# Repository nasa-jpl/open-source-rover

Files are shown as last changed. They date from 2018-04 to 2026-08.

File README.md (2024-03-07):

# JPL Open Source Rover Project

**NOTE**: For the previous major version of the OSR, please see [v3.1.0](https://github.com/nasa-jpl/open-source-rover/tree/v3.0.0).

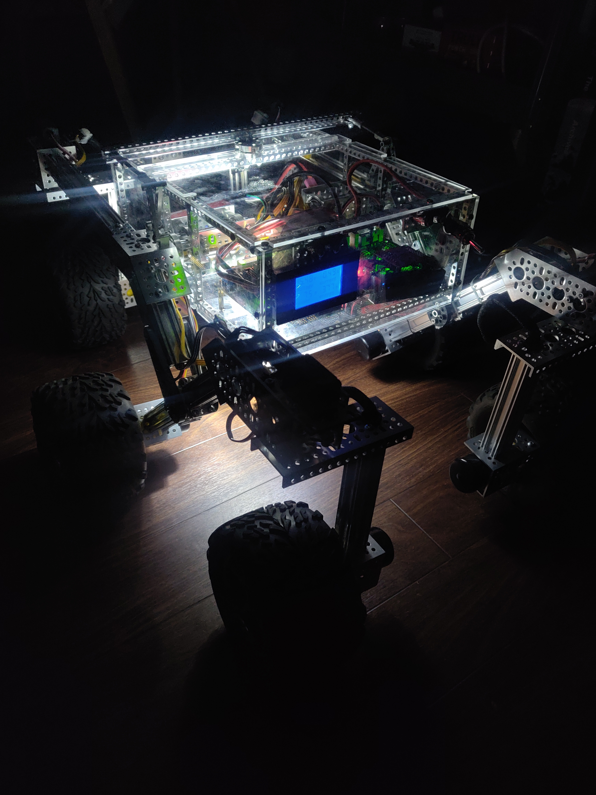
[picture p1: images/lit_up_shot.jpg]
|  |  |
| --- | --- |
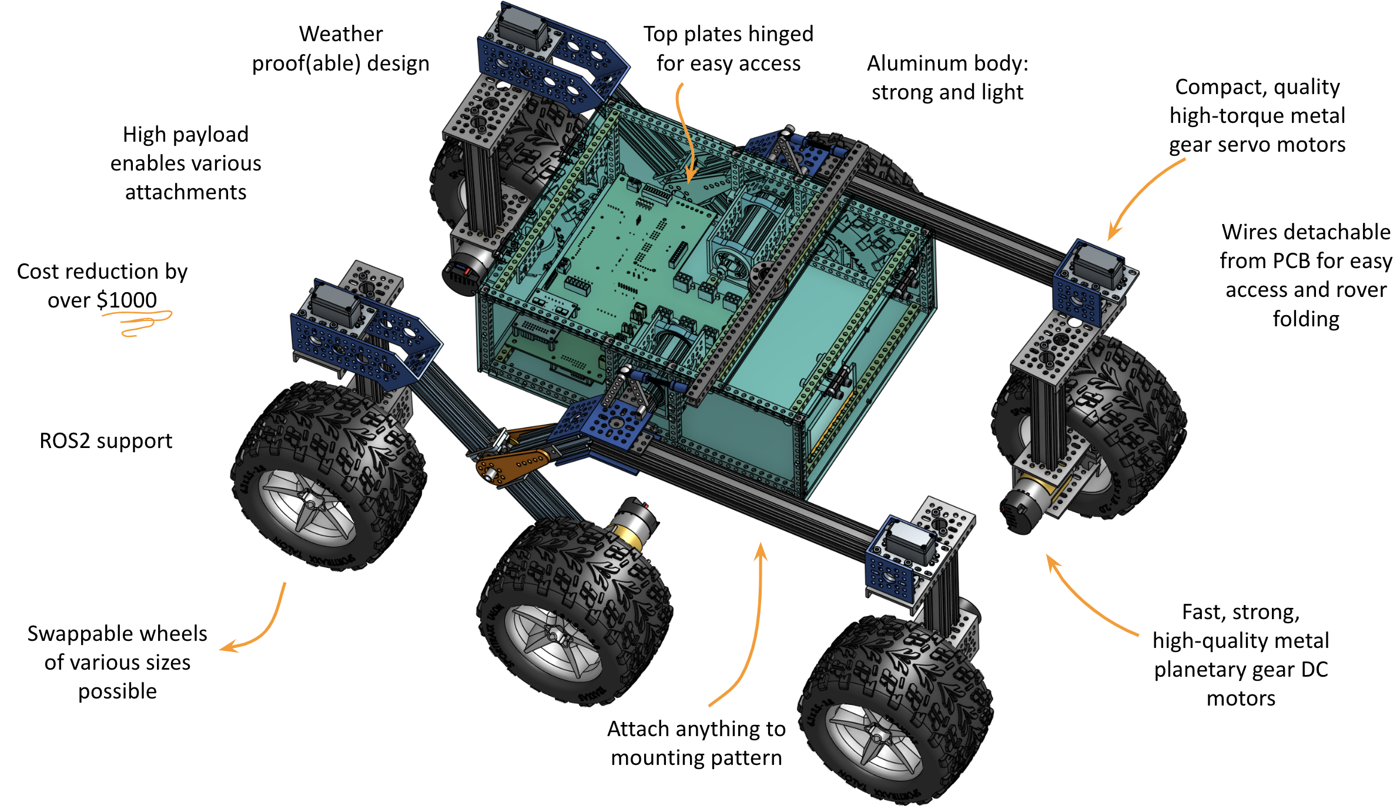
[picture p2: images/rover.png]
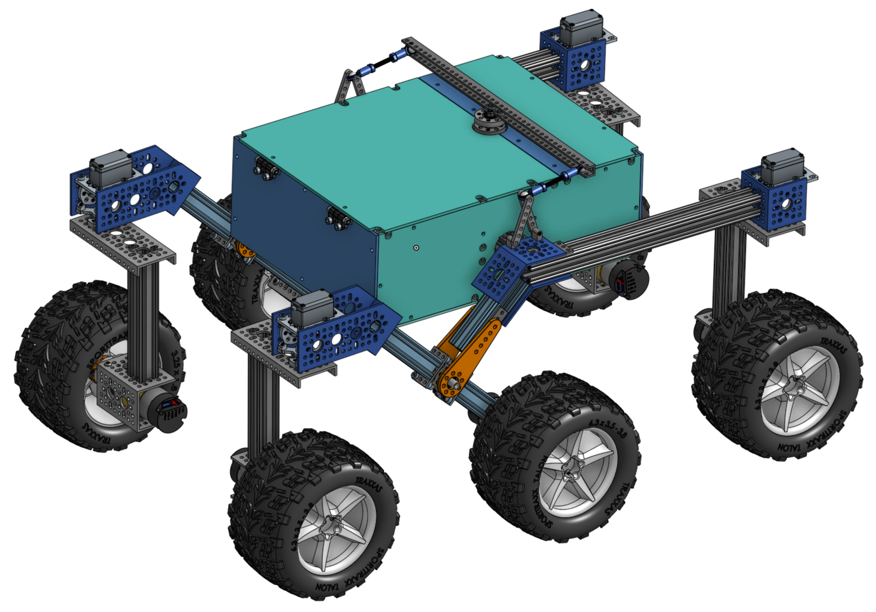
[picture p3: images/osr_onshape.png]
|  |  |

The JPL Open Source Rover is an open source, build it yourself, scaled down version of the 6 wheel rover design that JPL uses to explore the surface of Mars. The Open Source Rover is designed entirely out of consumer off the shelf (COTS) parts. This project is intended to be a teaching and learning experience for those who want to get involved in mechanical engineering, software, electronics, robotics but is also an excellent research platform for rugged terrain. No prior skills or knowledge is required.

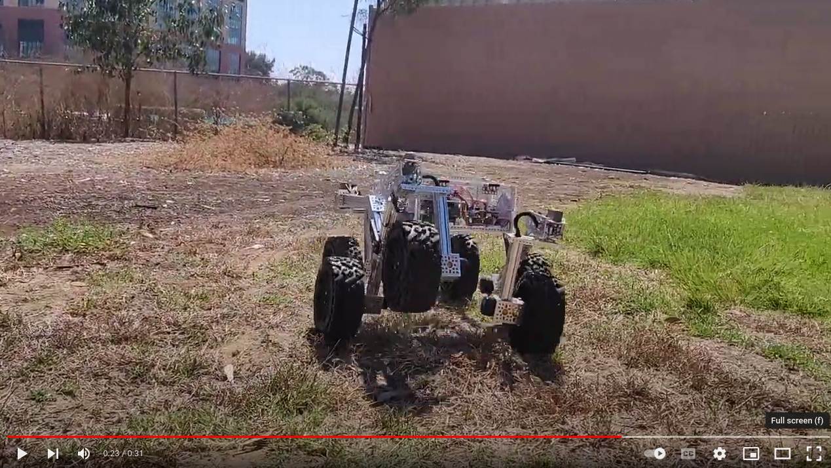
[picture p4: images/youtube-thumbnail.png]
Youtube video of OSR2 in action (https://youtu.be/exHqc_Vuifw)


A gallery of some community builds including previous versions of the rover can be found [here](examples/README.md).

## About the OSR

### Motivation

JPL is always looking to inspire the next generation of scientists, engineers, and roboticists to help us explore and learn about our solar system (and beyond!). We release the plans for this rover as a way to try and give budding enthusiasts a fun robotics project that will help teach them and get them involved in robotics sooner and at a lower cost.

### At a glance


<!-- TODO: insert terminology into gif or image: rocker bogie, ... -->

The OSR has been around since 2017 and has undergone many iterations. It is a premium and robust robot with a unique look, high customizability, and powerful abilities. The hardware and electronics were designed with expansions like a head display and robot arm in mind.

| spec | value |
| --- | --- |
| top speed | ~1.6m/s (~slow running, subject to motor selection |
| nb motors | 10 |
| structural material | aluminum |
| total cost | [~$1600](parts_list/README.md) (about the cost of a TurtleBot 3 Waffle) |



The OSR mostly uses parts from [GoBilda](https://www.gobilda.com) for the mechanical assembly. For GoBilda's (international) shipping options, see [here](https://www.gobilda.com/shipping-policy/).

Other open-source, cheaper alternatives exist but are slower, less strong, and are more fragile. See [Additional Projects](#additional-projects).

### Features

This rover is designed to function similarly to the 6 wheel rover designs on Mars and employs a few of the major driving mechanics that the mars rovers use to traverse rocky surfaces:

* **Rocker-Bogie:** The Rocker-Bogie suspension system allows all 6 wheels to continually be in contact with the ground while climbing over obstacles
* **Differential Pivot:** Allows weight to be mechanically offloaded from one side of the rover to the other while climbing
* **6-Wheel Ackerman Steering:** Driving and steering/turning mechanism that governs where the wheels point and how fast each of them will move.

A Raspberry Pi acts as the "brain" of this rover for its versatility, accessibility, simplicity, and ability to add and upgrade your own modifications. Any method with which you can communicate with a Raspberry Pi (bluetooth, WiFi, USB devices, etc) can be interfaced into the control system of the robot.

For a 7.2Ah battery and with some driving on rough terrain, expect to get at least 3 hours of drive time. Below chart was recorded while driving on rocky terrain and plots voltage, current draw, and commanded velocity over time. When the voltage drops below 13-14V, the rover will power down. You can increase drive time by getting a bigger battery and/or by having the rover carry a second battery that can be swapped out.

> *WARNING*: Be careful to not discharge a LiPo battery too far as that drastically lowers the lifetime of your battery and can potentially make it hard or impossible to recharge.

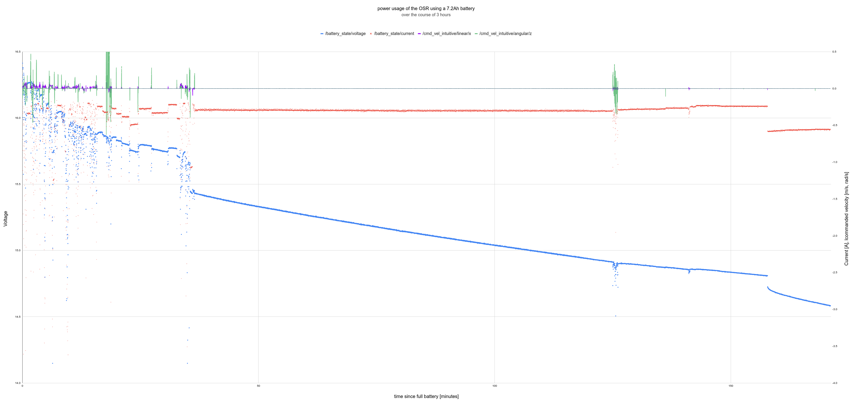
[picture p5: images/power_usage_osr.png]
power usage chart


## Join a community of hundreds of builders

Considering building one yourself? The best way to ask questions, reach maintainers, learn about modifications, and join the community of Open Source Rover builders is to join our Slack group:

<a href="https://join.slack.com/t/opensourcerover/shared_invite/zt-mfe0viua-FhcYsNb3S9vUra99uF3IBw">
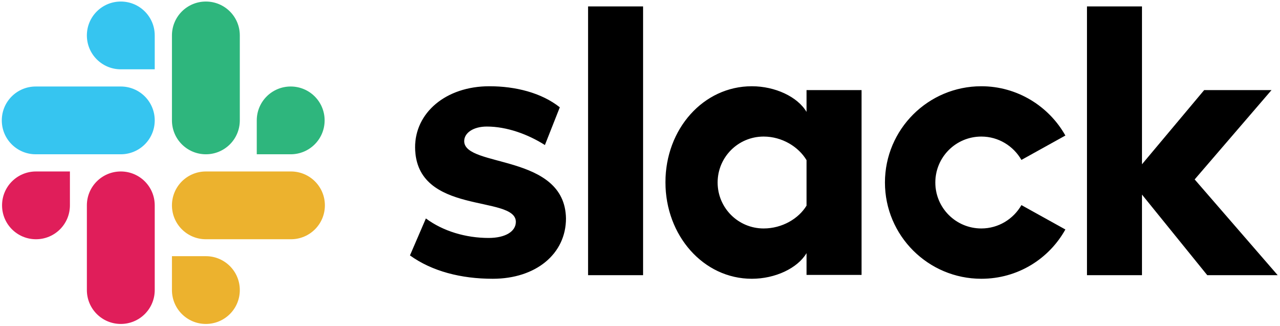
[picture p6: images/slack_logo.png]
  
</a>

**Note: JPL and Caltech have no official affiliation with this forum; it is run by individuals of the general public.** On these you can ask questions if you need help or clarification on any aspects of the project.  Additionally, you can post and promote any modifications or addons that you have created on this project. We highly encourage additions and modifications to be posted so that this project and community can grow.

### Maintenance Status

As an open-source hardware project, the rover is continuously improving. Please check [issues](https://github.com/nasa-jpl/open-source-rover/issues), [pull requests](https://github.com/nasa-jpl/open-source-rover/projects), and the Slack forum to see if any big changes are expected soon. The OSR project is proud to be Open-Source Hardware certified!

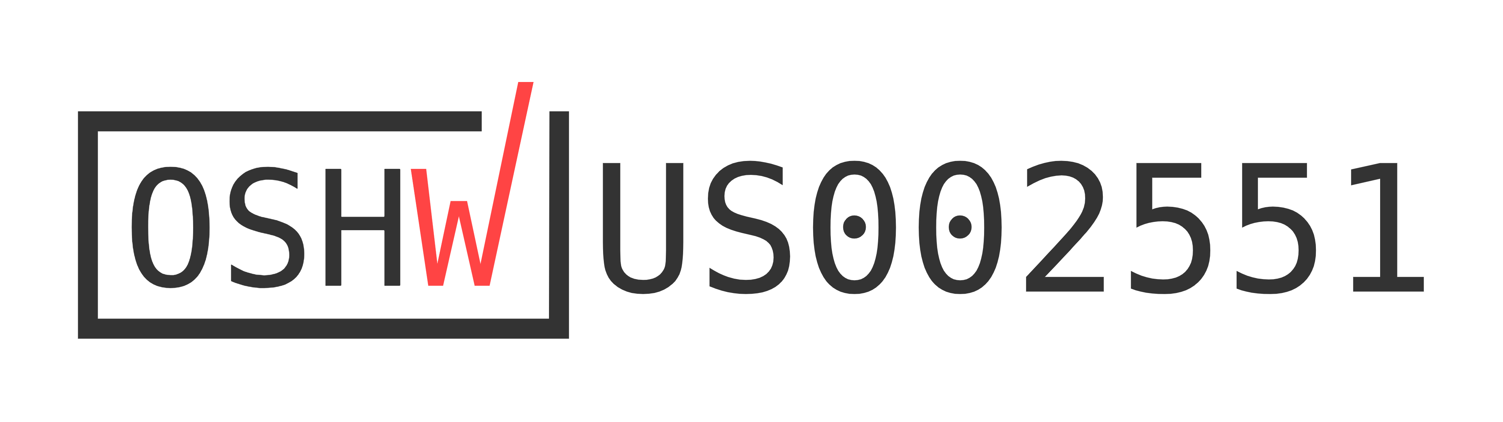
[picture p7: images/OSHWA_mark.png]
OSHW certification US002551 (https://certification.oshwa.org/us002551.html)


### Online 3D Model

You can view a 3D model of the latest version of the rover in your browser [at OnShape](https://cad.onshape.com/documents/e4f00b1a3d2edb1a84bbba1c/w/8ab8f394324bcc586236ef5d/e/9191e5ad2a70f387b419bc55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).

### Skills Necessary

This project has elements in mechanical assembly/fabrication, uses a host of electrical components, and has software that will run it all. In order to complete this project, you will need to have some experience in the following:

* **Fabrication/Machining:** All parts are Consumer Off-The-Shelf (COTS) parts and **no metal machining should be required** to complete the 'base' version of the rover. However for any optional expansions, it may be useful to have access to the following skills/tools:
  * Metal cutting using band saw/dremel
  * Drilling using drill press/hand drill
  * Filing and sanding for part cleanup
  * General Fabrication/Machining Safety
* **Electronics:** This project uses components like motors, motor controllers, and batteries. While prior experience with the following skills is not required, having access to someone who can help will save a lot of time:
  * Soldering
  * Electrical debugging
  * Wiring
  * Electrical Safety
* **Software:** The rover's brain is a Raspberry Pi. All code can be found in the [osr-rover-code](https://github.com/nasa-jpl/osr-rover-code) repository along with step-by-step instructions to set it up. Basic familiarity with Linux, ROS, Git, and Python will be helpful though.

Most of the above are skills that you can learn and pick up fairly quickly from watching videos and doing research on the internet, and throughout the project we try to give supplemental information on some of these as well. See the build documents for more information.

### Tools Necessary

This project assumes you have some standard tools to help assemble the project. If you do not have any of the optional tools, we provide examples of online services that you can use to have the parts fabricated and sent to you.

#### Mandatory tools

* Metric hex keys
* Pliers
* Wire Snips
* Wire Strippers
* Solder Iron
* Solder
* Digital Multimeter
* Wire strippers, e.g. [these](https://www.amazon.com/dp/B07DWVSR41/?coliid=ISMG8XMBILGFK&colid=1IM7RHK25RIBB&psc=0&ref_=lv_vv_lig_dp_it)

#### Optional Tools

* 3D printer
* Laser Cutter (for the body plates, online services available)
* Benchtop Power Supply (to test without using battery)
* Items for operating a Raspberry Pi (Keyboard, mouse, monitor, 5V micro USB power adapter)

### Expected time commitment

In our experience, this project takes no less than 100 person-hours to build, and depending on the familiarity and skill level of those involved could be significantly more. Experienced builders may be able to build this project in this amount of time.  However, this project is generally meant to be a teaching and learning tool.  Throughout the documentation, we try to give supplemental information for those who might be new to this kind of project.

## Getting Started

### Rover Build Roadmap

* **Stage 1:** [Order parts](#ordering-parts). You'll want to get started on this ASAP!

* **Stage 2:** [Create the wiring](electrical/wiring/README.md). The cables connect the Printed Circuit Board (PCB) in the body to each motor and integrate into the rocker-bogie and corner assemblies so they need to be built first.

* **Stage 3:** [Make the electronics](electrical/pcb/README.md): Soldering the PCB and installing into the rover along with peripheral connections. We'll also use the wiring to test your PCBs.

* **Stage 4:** [Make the mechanical assemblies](mechanical/README.md): the body, the two rocker-bogies, the drive and corner motor assemblies. The instructions will guide you through how to do these step by step while integrating the cabling from Stage 2. You'll then attach them into something that will start to look like a rover!

* **Stage 5:** Setting up and configuring the operating system rover code. The [Rover Code repo](https://github.com/nasa-jpl/osr-rover-code)'s README files will walk you through all necessary steps for getting the rover software up and running on the Raspberry Pi. These steps can be completed at any point during the project, all the way up to when all the electronics and mechanical parts are completed and you are ready to start driving and controlling the robot.

* **What's next?** Add your own upgrades! We chose Raspberry Pi as the brain of the project so that it should be easy to add, change, and upgrade to build exciting things on top of this already cool robot.  Some upgrade ideas to get you brainstorming: sonar for collision detection, IMU for orientation / closed-loop driving / obstacle mapping, camera for object identification and tracking, sensor packages (temperature, pressure, humidity), solar panels, or even a robotic arm!

### Ordering parts

#### Parts Lists

The [Parts List Readme](parts_list/README.md) contains all the parts necessary to build the entirety of the robot as it is listed in our documentation.

Note that educational builders may apply for a 15% discount at GoBilda by filling out [this form](https://form.123formbuilder.com/6143945/open-source-rover-edu-form). Make sure you do this on time as processing times may vary. 

You can select higher RPM motors (to drive your rover faster) at the sacrifice of max stall torque. A selection of motors that would integrate easily with the rest of the suggested rover design can be found at [GoBilda - 5203 series](https://www.gobilda.com/yellow-jacket-planetary-gear-motors/).
The rover design and the software can accommodate different wheel sizes if you find wheels you like better.

## Additional Projects

Take a look at these alternative Mars rover replicas:

* [Sawppy Rover](https://hackaday.io/project/158208-sawppy-the-rover)
* [ESA ExoMy](https://github.com/0xD0M1M0/ExoMy)
* [3D printed and driveable Curiosity/Perseverance inspired Rover](https://github.com/jakkra/Mars-Rover)

## Star History

Star History Chart (https://star-history.com/#nasa-jpl/open-source-rover&Date)

## Disclaimer

Reference herein to any specific commercial product, process, or service by trade name, trademark, manufacturer, or otherwise, does not constitute or imply its endorsement by the United States Government or the Jet Propulsion Laboratory, California Institute of Technology. Government sponsorship acknowledged.

Licensed under [Apache License 2.0](LICENSE.txt).

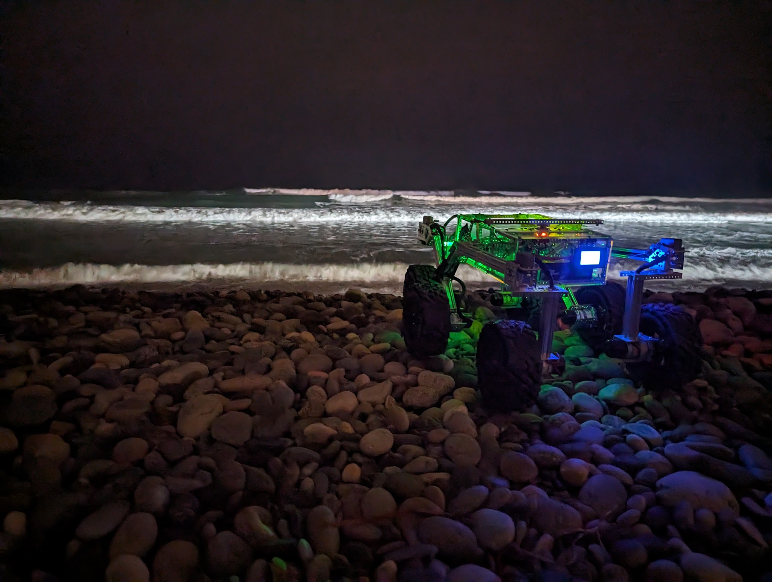
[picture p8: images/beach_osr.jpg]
OSR on the beach at night


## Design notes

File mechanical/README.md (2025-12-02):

# Mechanical Subsystem

The mechanical subsystem makes up the physical rover without any of its brains or electronics installed.

construction

The image below shows our suggested progression through the mechanical build process for this project. All individual subassemblies are meant to be completely parallelizable, so each individual subassembly could be built on its own at the same time. Once all the subassemblies are finished, there is one mechanical integration process where each of the subassemblies is integrated together to create the final rover body. Along with the pictures in each folder's README document, open the [OnShape model](https://cad.onshape.com/documents/e4f00b1a3d2edb1a84bbba1c/w/8ab8f394324bcc586236ef5d/e/9191e5ad2a70f387b419bc55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) so you can see what goes where and spin it around. Note that the OnShape model does not have all screws included to keep the model speedy and light.

## Building the subassemblies

Click on the images to get started on a subassembly!

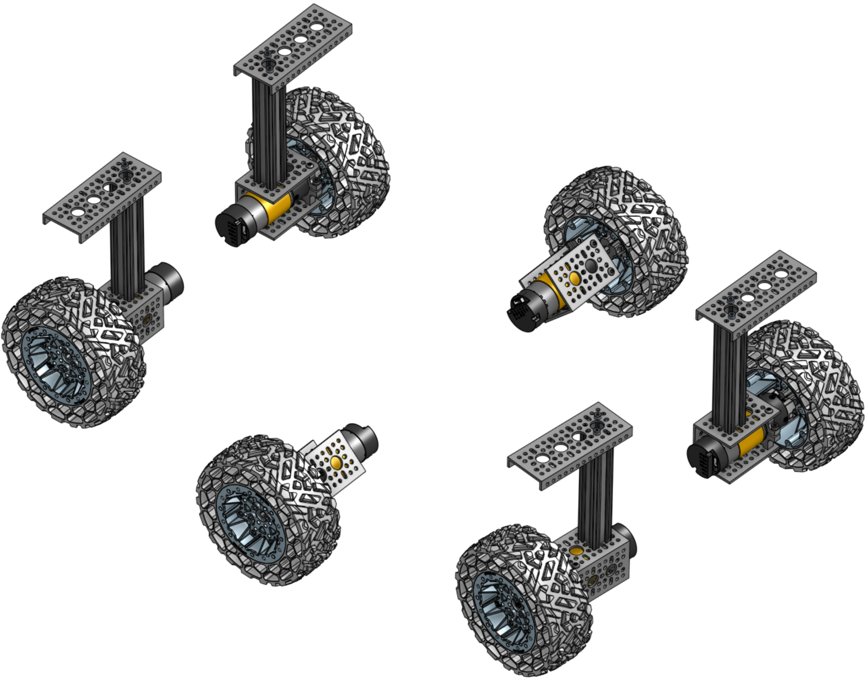
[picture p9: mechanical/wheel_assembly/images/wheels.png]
wheel assy
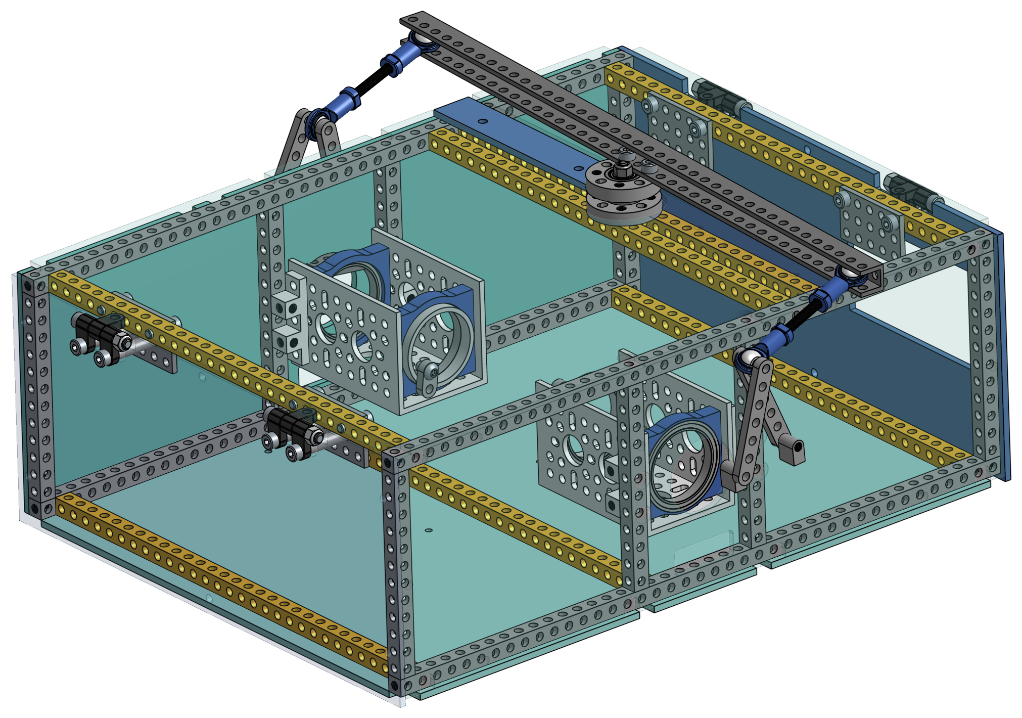
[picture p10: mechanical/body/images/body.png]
body
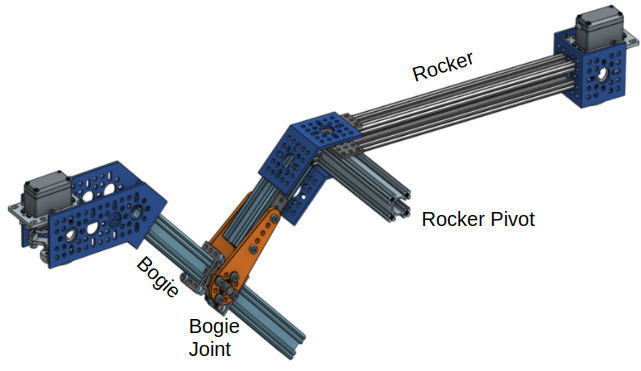
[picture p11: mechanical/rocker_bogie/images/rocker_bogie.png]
rocker bogie
|  |  |  |
| --- | --- | --- |

## Putting it all together

If you haven't already, now is a good time to attach the PCBs to the bottom body plates using the standoffs. The body plates have holes that correspond to where the standoff screws should go.

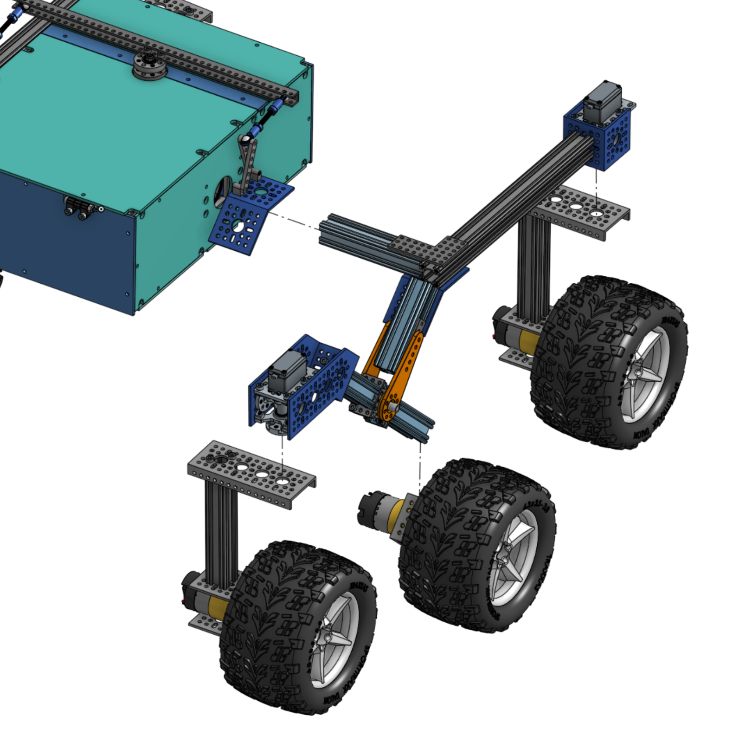
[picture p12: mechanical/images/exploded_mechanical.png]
exploded view

Inserting the left rocker-bogie in the body. Note that the 45 angle bracket in blue should already be attached to the rocker-bogie and the wheels should not be attached yet. A 32mm ID round spacer that should be installed below is also not seen on this image.
**I didn't have space on the outside of the body, just one spacer in the center**

### Inserting the rocker-bogies in the body

Line up the rocker-bogies with the body such that they can be easily inserted. It helps to put the body on a box such that the holes line up with the rocker-bogie axes. Slide a 32mm internal diameter (ID) spacer around the wires and onto the rocker-bogie axis. Then, carefully insert the wires extending from the rocker-bogie axis through the body plate hole and large diameter bearings and into the body, immediately followed by the axis itself. Repeat for the other side.

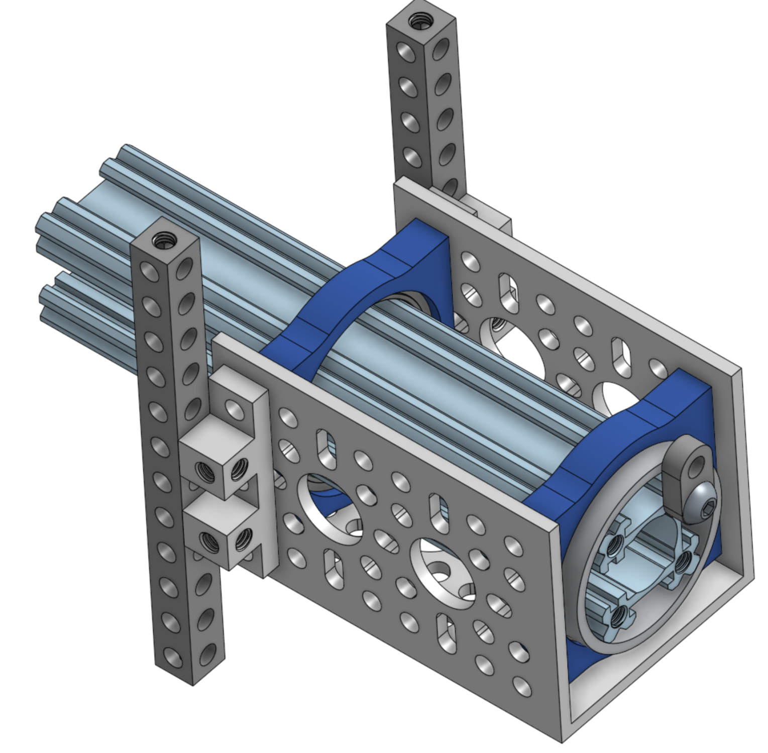
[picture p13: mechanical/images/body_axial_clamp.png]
inserting the rocker-bogie axis into the body axis assembly

Inserting the rocker-bogie axis into the body axis clamp. The rocker-bogie is not shown. The cables come out of the axis on the bottom right.

Secure the body axis to the body using another 32mm ID spacer and flat 2-hole bracket + button screw. Repeat for the other side.

### Attaching the differential pivot to the rocker-bogies

Attach the differential pivot legs to the rocker-bogie 45 degree brackets using M4x8 screws.  It may be easier to unmount the blocks, attach them to the bracket, then attach the pivot legs to them as shown in the sequence below.  A curved pair of needle-nose pliers or a hemostat is helpful to secure the M4x8mm screw while placing the block on the top, as it's hard to reach.  The button head screw that attatches to the inside leg is a bit tight.

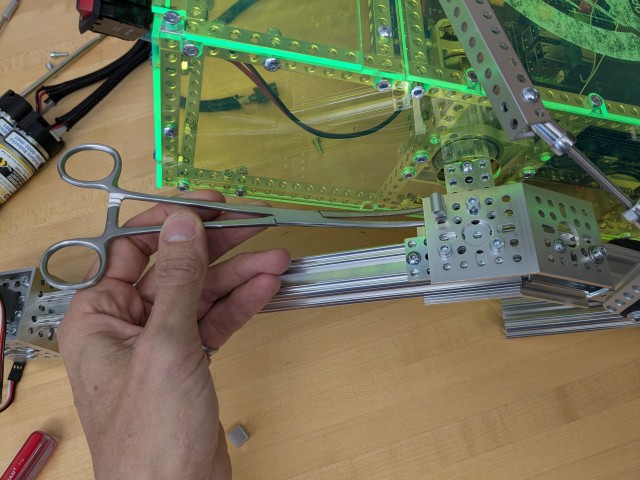
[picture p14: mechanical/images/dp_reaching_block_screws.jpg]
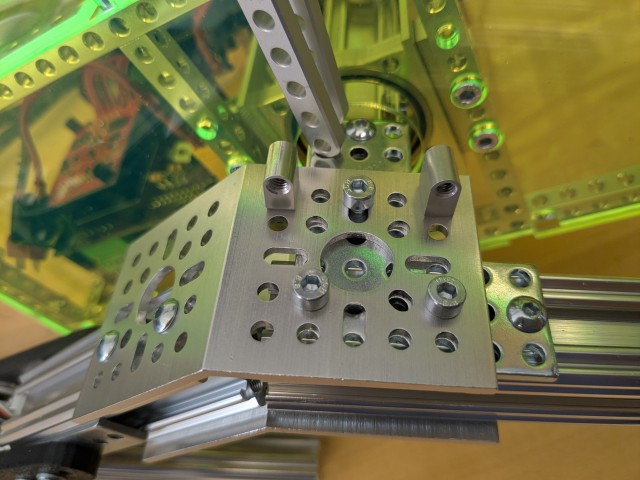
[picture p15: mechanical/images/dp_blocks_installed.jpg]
|| |
| --- | --- |
| Holding the blocks in place | Blocks Installed |

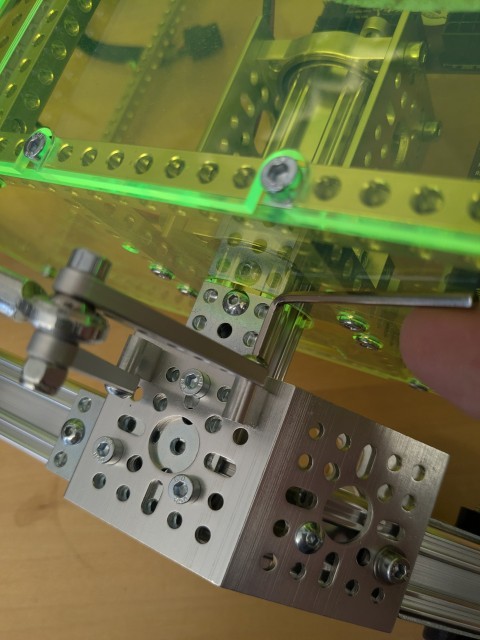
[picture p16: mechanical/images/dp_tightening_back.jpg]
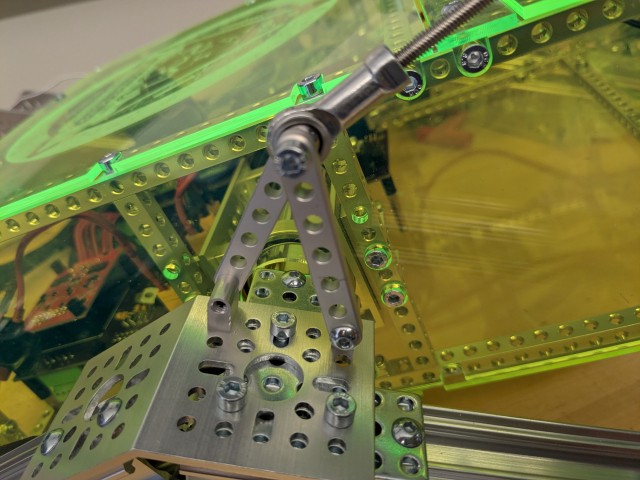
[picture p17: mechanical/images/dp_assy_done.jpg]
|| |
| --- | --- |
| Tightening the back leg | Differential Pivot Installed.

### Attaching the middle drive motors

With the help of someone else, carefully flip the rover over so we can attach the motor assemblies.

Connect the two drive motor U-channels to the rocker bogie middle legs using 3 button screws. Then insert the motor into the U-channel and secure the clamp around the motor's gearbox to the U-channel using 4 socket M4 screws. It helps to have another person around here as well to hold the motors so they don't dangle on the cables.

### Attaching the corner assemblies

Using 3 socket M4 screws, attach each corner assembly to the output shaft bracket of the servo. Making sure you connect the right corner assembly to the right side. Flip the rover over again and route the corner cabling through a hole in the bracket holding the servo. The bullet connectors and DuPont connectors from the rocker bogie and corner assemblies should meet here.

> **tip**: Now is a good time to do another connectivity check. Using your multimeter, confirm that each wire connects all the way through.

> **Maintenance note**: The corner servo gearset can sometimes be damaged in operation. See [here](servo_gear_replacement/README.md) for a guide on repairing your corner servos.

Finally, insert the PCI-E connectors inside the body and the DuPont connectors for the servo motors into the appropriate receptacles on the PCB. The silk screen lettering on the PCB informs which wire should go where. Once inserted, make sure the rocker-bogies can rotate relatively freely around the body by lifting the wheels up.

If all goes well you're done with the mechanical and electrical stages and you're ready to install the software!

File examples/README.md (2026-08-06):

# Builders' gallery

OSRs in the wild and under construction! Please [add your rover](#Instructions-for-adding-your-build) and add updates and pictures here as it evolves.

# <ins>V2 Rovers</ins>

## Coast-Ex

| <image src="images/coast-ex/coast-ex-cliff-view.jpg" height="150"> <image src="images/coast-ex/coast-ex-waterfront.jpg" height="150"> <image src="images/coast-ex/coast-ex-lidar.jpg" height="150"> <image src="images/coast-ex/coast-ex-side-view.jpg" height="150"> [<image src="images/coast-ex/coast-ex-video-thumbnail.jpg" height="150">](https://youtube.com/playlist?list=PLEVE4pbtqQmY) |
|:-:|

<details>
  <summary>Expand to learn more about this build!</summary>

### Background

COAST-EX was built in 2026 as a collaborative internship project involving SCIENTEAMA, the M2C laboratory (CNRS) and ESIX Normandie.

Our objective is to investigate how the JPL Open Source Rover can be adapted into a low-cost, modular platform for the digital surveying of beaches and coastal environments. The rover is intended to support repeatable field acquisitions for terrain mapping, LiDAR-based localization, photogrammetry, and, in future developments, other scientific sensors such as ground-penetrating radar.

The first prototype was assembled and integrated by engineering student Théo Etheve at ESIX, under the joint supervision of Xavier Pellerin Le Bas at SCIENTEAMA and Laurent Froideval at CNRS.

Initial field trials were conducted on sand, gravel, and uneven terrain to evaluate the rover's mobility and its suitability for coastal fieldwork. Real-time LiDAR SLAM was also successfully tested while the rover was moving.

### Modifications

* Replace Polulu 5V D24V150F5 by a cheaper ANGEEK 200W 15A XF0374 (https://www.amazon.fr/-/en/dp/B07ZH5QDSS?ref=ppx_yo2ov_dt_b_fed_asin_title)
* Added a top-mounted LiDAR sensor
* Integrated real-time LiDAR SLAM for mapping and localization
* Adapted the onboard software configuration to operate the LiDAR and SLAM system

### Current development

Future developments will focus on autonomous navigation, repeatable surveying trajectories, terrain mapping, camera-based acquisition, and the integration of additional coastal monitoring sensors.

### Media

* [Field test videos](https://youtube.com/playlist?list=PLEVE4pbtqQmY)

</details>

## Phoenyx-I ([PUCRA](https://github.com/PUCRA/Phoenyx-I))

| <image src="images/Phoenyx-I/Phoenyx-I 1.jpg" height="175"> <image src="images/Phoenyx-I/Phoenyx-I 2.jpg" height="175"> <image src="images/Phoenyx-I/Phoenyx-I 3.png" height="175"> |
|:-:|

<details>
  <summary>Expand to learn more about this build!</summary>

### Background
We are a robotics association formed by university students.

We decided to participate in the SENER CEA Bot Talent 2025 competition in order to learn and deepen our knowledge in robotics. As a result, we achieved great success, winning both the Design Award and the Overall Award, and successfully completing three challenges: perception, localization, and control. The competition was focused on using the JPL rover to carry out the challenges.

After the competition, we carried out several demonstrations and implemented multiple improvements to both the robot and its software in order to continue learning and improving the system.

### Modifications
* Added an Orbbec Astra Pro Plus (RGB-D camera)
* Added a YDLidar X4
* Added an Adafruit BNO055 IMU
* Added an Arduino to control a NeoPixel LED to indicate the robot state
* Added an emergency button
* Added a ventilation system with dust protection
* Replaced the RoboClaw 2x7 with the RoboClaw 2x15 motor drivers
* Added PLA covers for decoration and protection of motors, servos, robot profiles, and sensors

</details>

## jerrys_rover ([jerryok826](https://github.com/jerryok826/rover-monitor  ))
| <image src="images/jerrys_rover/rover_lawn_1.jpeg" height="175"> <image src="images/jerrys_rover/rover_monitor_pcb.jpg" height="175"> 
|:-:|

<details>
  <summary>Expand to learn more about this build!</summary>

### Background
I always wanted to build an outdoor rover so I started building the JPL rover in May 2025. It took me a couple of months to build it but it was great fun. I learned a lot along the way especially after not using Loctite, the screws loosened and left me with a trail of nuts and bolts in the backyard.
### Modifications
* Added OLED info display with shutdown and run buttons.
* Audible alarm for of battery state.
* Make one yourself [here](https://github.com/jerryok826/rover-monitor)

</details>

## Resilience (res) ([murphcj](https://github.com/murphcj))
| <image src="images/Resilience/Resilience_Lighthouse.jpeg" height="175"> <image src="images/Resilience/Resilience_Ocean.jpeg" height="175"> <image src="images/Resilience/Resilience_at_School.jpeg" height="175">
|:-:|

<details>
  <summary>Expand to learn more about this build!</summary>

### Background
Resilience was our first foray into robotics and has done several show-and-tells at the local elementary schools (driving over kids, Teachers, and the Principal!). The name comes from the book "A Rover's Story" by Jasmine Warga. This was a family project we started in January of 2024 and finished in February 2025. We hope to add more to this build in the future.

### Modifications
* TBD...

</details>

## Scout ([Scout](https://github.com/igillespie))
| <image src="images/scout/scout_1.jpeg" height="175"> <image src="images/scout/scout_mast.jpeg" height="175"> <image src="images/scout/website.jpeg" height="175"> |
|:-:|

<details>
  <summary>Expand to learn more about this build!</summary>

### Background
This was a family project we started in November of 2024. Our goal for this project was to build a rover that we could remotely teleoperate from our house and have the rover drive around our town. 

### Modifications
* Pan and tilt mast that houses a camera. Pan and tilt controlled by two servos.
* BNO085 IMU to help improve odometry
* Currently the rover stays connected to the internet via a Verizon "Jetpack" cellular puck. Stretch goal is to add a more integrated cellular connection with GPS
* Custom website that allows us to control the rover and its mast and monitor its status
* Flask and websockets to manager the website and streaming data

</details>

## TMUMechE ([TMUMechE](https://github.com/TMUMechE/open-source-rover))
| <image src="images/TMUMechE/RoverPic1.png" height="175"> <image src="images/TMUMechE/RoverPic2.png" height="175"> |
|:-:|

<details>
  <summary>Expand to learn more about this build!</summary>

* Project began in January 2024 with a team of 3 seniors studying mechanical engineering at The Master's University, and the help of a senior in computer science
* Intended to be a platform for future classes at The Master's University to build on the work we have started

### modifications
* Check back here for modifications coming soon!

</details>

## Bobert ([Adriel](https://github.com/abust005/open-source-rover))
| <image src="images/bobert/bobert_front.jpg" height="175"> <image src="images/bobert/bobert_side.jpg" height="175"> <image src="images/bobert/bobert_back.jpg" height="175"> |
|:-:|

<details>
  <summary>Expand to learn more about this build!</summary>

* Construction started in October 2023 as a first personal dive into robotics 
* Intended as a learning experience, and as a general robotics platform for exploring computer vision and navigation algorithms

### modifications
* **OAK-D + mount**: Bobert has an original run OAK-D from the first Kickstarter for his eyes, plus a custom pan-tilt mount I designed and had printed in nylon with multi-jet fusion (MJF). The mount uses two pancake stepper motors driven my a SPI-controlled stepper driver board
* **Tool rack**: For field maintenance and repair, I've added a small rack using some wooden dowels and some 3D-printed brackets to hold my Wera ratchet in place on Bobert
* **On/off switch mount**: To prevent the on/off switch just flopping around, I've added a small 3D-printed switch mount

</details>

## Raf the Rover ([Achille](https://github.com/Achllle))

| <image src="images/raf/raf_roof_rack.jpg" height="150"> <image src="images/raf/osr_outside.jpg" height="150"> |
|:-:|

<details>
  <summary>Expand to learn more about this build!</summary>
  
### background

* This is my second rover! I built the first one [Robert the Rover](#robert-the-rover-achille) in 2019. This version is the original v2 of the OSR, which I lead the mechanical design of.
* It was featured on [Hackaday](https://hackaday.com/2023/09/16/open-source-rover-gets-an-update-for-easier-building/)

### modifications

* I built a roof rack for it so that it could carry stuff around. As you can see from my first rover's mods, I switched to a roof payload holder instead of a trailer cart since that makes doing autonomy easier and lowers the chance of slipping.

</details>

## Samwise ([Eric](https://github.com/ericjunkins))

| <image src="images/samwise/samwise_front.jpg" height="150"> <image src="images/samwise/samwise_side.jpg" height="150"> <image src="images/samwise/ring_bearing.jpg" height="150">|
|:-:|

<details>
  <summary>Expand to learn more about this build!</summary>
  
### Background

* This is a custom spin-off of the OSR V2 design, utilizing mostly the same electronics and software stack, but made out of a combination of laser cut aluminum and 3D printing technologies such as MJF, SLA, and SLS. It was inspired by my partner who asked for a ring bearer robot at our wedding, and this project was particularly special to us as I was working on designing the very first Open Source Rover at JPL when we met. 

### Modifications

<table>
  <tr>
    <td width="50%">
      Custom channels, creating the structure and allowing cables to be routed through the interior of the robot, sealing from elements, and keeping cables well protected. 
    </td>
    <td>
      <image src="images/samwise/rocker_bogie_inside.PNG" >
    </td>
  </tr>
  <tr>
    <td width="50%">
      Added a servo and servo mounting block + gears in order to give the head an articulated axis, making it so I could make the head rotate around. Hollow tube supports mounts the head to run cables, and mounts an LCD screen at the top. 
    </td>
    <td>
      <image src="images/samwise/head_pivot_mechanism.PNG">
    </td>
  </tr>
  <tr>
    <td width="50%">
      Wrote a ROS backend + FastAPI, and React frontend to display either a cute face, or diagnostic information about what's happening on the robot. Gui shows things like wheel speeds, servo positions, battery voltage level, and a few error/faults.
    </td>
    <td>
      <image src="images/samwise/gui.PNG">
    </td>
  </tr>
  <tr>
    <td width="50%">
      Added corner latches that swing up/down and attach via magnets, allowing me to lock out the corners so they can't move for transportation. 
    </td>
    <td>
      <image src="images/samwise/corner_stops.jpg">
    </td>
  </tr>
</table>

</details>

# <ins>V1 Rovers</ins>

## JPL Rover

| <image src="images/jpl_rover/rover_at_open_house_1.jpg" height="350"> <image src="images/jpl_rover/rover_at_open_house_2.jpg" height="350"> |
|:-:|
| <image src="images/jpl_rover/jpl_rover_1.jpg" height="350"> <image src="images/jpl_rover/dsub.jpg" height="350"> |
|:-:|

<details>
  <summary>Expand to learn more about this build!</summary>
  
* Constructed in 2017, upgraded many times since!
* JPL has used this rover for many different events, from JPL/Mars outreach events, taking it to schools, local robotics clubs, and even a few robotic conferences!
* Maintained by a few different JPL employees over the years
  
### modifications

* Annodization! Before assembly of this version we got the metal pieces annodized a mix of red/black
* Micro D-Sub connectors at each of the rocker-bogies, so that both can be taken off easily and rover can be transported much easier!
  * [micro d-sub male](https://www.digikey.com/en/products/detail/itt-cannon-llc/M83513-03-D04N/2432917)
  * [micro d-sub female](https://www.digikey.com/en/products/detail/itt-cannon-llc/MDM-25SH006B/10491746)
* JPL Beanie! :)
  
</details>

## Robert the Rover ([Achille](https://github.com/Achllle))

| <image src="images/robert/robert1.png" height="150"> <image src="images/robert/robert2.jpg" height="150"> |
|:-:|

<details>
  <summary>Expand to learn more about this build!</summary>
  
### background

* I started construction in December 2019. Robert took his first steps about 3 months later.
* I use the rover for fun,
* I help maintain the two repositories. I'm a robotics engineer by training and happy to help with anyone stuck or with ideas. The best way to reach me is via Slack.

### modifications

* **bigger battery**: Robert runs off of [this 9Ah LiPo battery](https://www.amazon.com/gp/product/B07YP73LMX/ref=ppx_yo_dt_b_search_asin_title?ie=UTF8&psc=1)
* **RC**: For outdoor roving, I use a long-range [transmitter](https://www.amazon.com/gp/product/B08CKWZWPR/ref=ppx_yo_dt_b_asin_title_o03_s00?ie=UTF8&psc=1) and [receiver](https://www.amazon.com/gp/product/B07ZK1R32H/ref=ppx_yo_dt_b_asin_title_o02_s00?ie=UTF8&psc=1) from Spektrum.
* **sensor stack**: I mounted a lidar on top of my rover to allow for 2D mapping, localization, and navigation. I also have mounted (variations of) two monocular cameras, an IMU, and depth cameras to it. Details in [my blog post](https://www.freedomrobotics.ai/blog/how-to-pick-navigation-sensors-for-autonomous-mobile-robot).
* **toy trailer**: I bought this [toy trailer](https://www.amazon.com/gp/product/B0002HZQGO/ref=ppx_yo_dt_b_search_asin_title?ie=UTF8&psc=1) so that Robert can carry a payload. I attached it to Robert using a repurposed wrench and a collar clamp. It's not very robust but [it does the trick](https://youtu.be/caqx-S-_gv8)!
* **handle**: I used a strong piece of rope and a small piece of PCV tubing (handle) to lift the rover off the ground so I could carry it up and down stairs.
  
### blogs

  1. [Deploying on Mars: NASA-JPL Open Source Rover](https://www.freedomrobotics.ai/blog/building-the-nasa-jpl-open-source-rover)
  2. [Deploying on Mars: How to Pick Sensors to Enable Navigation for Your Autonomous Mobile Robot (AMR)
](https://www.freedomrobotics.ai/blog/how-to-pick-navigation-sensors-for-autonomous-mobile-robot)
  3. [Deploying on Mars: Rock solid Odometry for Wheeled Robots
](https://www.freedomrobotics.ai/blog/tuning-odometry-for-wheeled-robots)
  4. [Deploying on Mars: Rock solid Odometry for Wheeled Robots](https://www.freedomrobotics.ai/blog/deploying-on-mars-mapping-localization)

</details>

## Paddy-Rover ([Kit](github.com/apollokit))

| <image src="images/paddy/paddy1.jpg" height="150"> <image src="images/paddy/paddy2.png" height="150"> |
|:-:|

<details>
  <summary>Expand to learn more about this build!</summary>

  * I built Paddy through the winter of 2019-2020. She was (kinda) a covid baby!
  * It's been a great learning experience building and maintaining Paddy.
  * I help maintain the two repositories!
  
</details>
  
## Sinuhe's rover

| <image src="images/sinuhe/sinuhe1.png" height="250"> [<image src="images/sinuhe/video_icon.png" height="250">](https://youtu.be/jEhQtxJgvEM) |
|:-:|
  
<details>
  <summary>Expand to learn more about this build!</summary>

  This project help us get through covid year 2020!
  
  | <image src="images/sinuhe/electrical1.png" height="250"> <image src="images/sinuhe/electrical2.png" height="250"> |
  |:-:|
  
</details>
  
## Alex' rover
  
https://user-images.githubusercontent.com/14060847/160306700-88ff7ab6-efe0-483a-8637-53a57874fb1f.mp4
  
## Roverto ([toebes](github.com/toebes))

| <image src="images/roverto/roverto.jpg" height="150"> <image src="images/roverto/roverto_climbing_wheel.jpg" height="150"> |
|:-:|
<details>
 <summary>Expand to learn more about this build!</summary>

Built by the [Cardinal Gibbons Robotics](https://www.cghsnc.org/campuslife/co-curricular/robotics) team for use at outreach events.  Roverto has been to a few places, but is most at home on our [Mars Map courtesy of the Aldrin Foundation](https://aldrinfoundation.org/giant-mars-map/).  With it Roverto has been to:

* Astronomy days at the [North Carolina Museum of Natural Sciences](https://naturalsciences.org/) Three times.  One time Roverto had the opportunity to try and drive over a full size Curiosity wheel.  The last time we rand that event, there were over 14,000 attendees.
* [Galaxycon](https://galaxycon.com/pages/raleigh) Twice!
* The [North Carolina Transportation Museum](https://www.nctransportationmuseum.org/)
* Many events at [Cardinal Gibbons High School](https://www.cghsnc.org/).

### Enhancements

* The drive motors have been replaced by [Rev Robotics Core Hex Motors](https://www.revrobotics.com/rev-41-1300/) to give better torque
* The LED display has been updated with a [10" HDMI Touchscreen](https://www.sunfounder.com/products/10inch-touchscreen-for-raspberrypi).  We have a custom HTML web page which shows Roverto's face.
* Roverto has a custom development stand that lifts all the wheels off the ground for easy testing.

### Media
* [@robotics_cghsnc](https://twitter.com/robotics_cghsnc)

</details>

## USAi Labs AUDACITY ([JHPHELAN](github.com/JHPHELAN))

| <image src="images/AUDACITY/Houston-Robotics-Fidelity cropped.jpg" height="150"> <image src="images/AUDACITY/IMG_4751.JPG" height="150"> <image src="images/AUDACITY/IMG_3927.JPG" height="150"> <image src="images/AUDACITY/IMG_3931.JPG" height="150"> |
|:-:|
| AUDACITY 01 video (https://www.youtube.com/watch?v=n0Rx8EbABIY) |

<details>
  <summary>Expand to learn more about this build!</summary>
  
  ### Background
  * Started August 2019 as soon as we heard about the release of the NASA-JPL Open Source Rover
  * Named first version "Fidelity" to be as close to the NASA-JPL version as possible
  * Once initial parts had arrived, had a "part picking party" 
  * - with instructions from the manual for various sub-assemblies passed out, ziplock bagged & labeled
  * Sub-assemblies then assembled in groups
  * Had first roll-out almost exactly 1 year later after multiple delays, modifications, and frustrations as seen in .mp4 above
  
  ### Modifications
  * New version of rover named "AUDACITY" to be as boldly upgraded as possible to ultimately be autonomous
  * Raspberry Pi 3 >> Raspberry Pi 4b 4GB.  Perhaps later >> Jetson NANO to permit onboard AI "on the edge"
  * Raspbian >> Ubuntu 20.04
  * hand-coded Python >> ROS >> ROS2 Foxy
  * Upgraded PCB.  Looking forward to Rev F!
  * Upgraded drive & steering motors
  * Custom front/back acrylic panels
  * Emergency "Bop to Stop" switch.  Abandoned to free up room
  * Key fob remote power "Kill Switch" for range safety.  
  * - to substitue RoboClaw e-stop pins in future to stop motors but not CPU
  * Arduino driven LED "head" >> onboard LCD monitor - work in progress
  * Addition of cameras: Picamera, USB camera, Intel RealSense D450 Depthcamera, OAK-D Depthcamera |
  * - all works in progress and fraught with frustrations
  * Front bright LED "headlights" wired in parallel with drive motors.  Since polarity matters, only on when driving forward
  * Plan steering motors >> servos at some point

  ### External links
  1. [USAi Labs and Houston Community College  First rollout of rover](https://www.youtube.com/watch?v=2Wdgss0q63s)

</details>

## Instructions for adding your build

1. We'll be needing a little bit of git skills here. Although not strictly necessary, it helps to take a look at some tutorials on contributing using git & GitHub. Here are the basic steps.
   1. install git on your computer. On Linux, that means `sudo apt-get install git`
   2. Fork this repository by clicking the `Fork` button in the top right corner of the GitHub page.
   3. 'Clone' your fork to your computer by clicking the green `Code` button and copying the link. Type in `git clone` into your terminal and paste the link you just copied.
   4. Create a new branch and switch to it. `git checkout -b ourrovername_gallery`
   5. You're ready to start making changes! You can use any text editor of your liking, like [VS code](https://code.visualstudio.com/).
2. copy over someone else's section and adjust it to include your build's information. Add your entry to the top of the relevant section (V1 or V2). To keep this compact, add any text and details to the collapsible section (within the `<details> </details>` tags).
3. Create a new folder within [the images folder](./images) and add your rover's pictures to it.
4. Change the image links to point to your images. The format for that is `image src="images/your_folder_name/your_picture.jpg"`.
5. Commit your changes with git.
   1. in the terminal, navigate to this folder. `git status` should show that there are changes and new files.
   2. use `git add folder_name/file_name` for each change you want to include to stage those files.
   3. Commit these changes: `git commit -m "Adding my rover to the OSR gallery!"`
   4. Upload them using `git push origin ourrovername_gallery`, replacing `ourrovername_gallery` with the branch name you created earlier.
6. Create a Pull Request (PR) to suggest merging your code into the main branch.
   1. Navigate to the repository's [pull request page](https://github.com/nasa-jpl/open-source-rover/pulls) on GitHub. Click 'New pull request'.
   2. click 'compare across forks'.
   3. Select your fork from the head repository dropdown and pick your branch.
   4. click 'create pull request'. GitHub will take you to a page where you can create a title of your suggested changes and a description.
7. Wait for a maintainer to review your changes. They might ask you to make changes if something doesn't look right. Once the PR has been greenlighted, your changes will be added to the main branch!

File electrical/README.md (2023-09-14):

# Electrical

Please refer to the [PCB assembly](pcb/README.md) and [wiring](wiring/README.md) instructions.

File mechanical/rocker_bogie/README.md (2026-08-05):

# Rocker-Bogie Suspension

The Rocker-Bogie is the suspension system that enables the rover to climb aggressive obstacles. The design allows all 6 wheels to be in contact with the ground as much as possible, increasing traction.  The suspension system on a typical consumer vehicle can traverse obstacles about half the height of one wheel; the Rocker-Bogie suspension system can traverse obstacles over 2 times the height of the wheel.

rocker bogie

## Features

* Modular link lengths give the ability to customize rover geometry
* Optimized for climbing in the forwards direction
* Rigid support structure resists lateral bending/twisting about the Bogie joint

## Mechanical Interface/Attachments to Rover

* Servo block output shafts connect to corner motor assemblies
* rocker-bogie connects to the body axis clamp via two brackets that are detailed in the [body assembly section](../body/README.md#assemble-the-bearing-support-structures-that-connect-to-the-rocker-bogie)
* middle drive motor connects to the extruded shaft at the bottom

## Assembly

You will be creating two almost identical assemblies. Below instructions are for one side. We recommend building one side first rather than trying to build both sides in parallel, that way you'll be able to make the other side faster. Before you start building, familiarize yourself with the details of this assembly, in particular because you'll be building two assemblies that are mirrorred. Specifically, you'll want the open slits on the bogie to be facing the same side:

| close up showing slits                         |
| ---------------------------------------------- | 
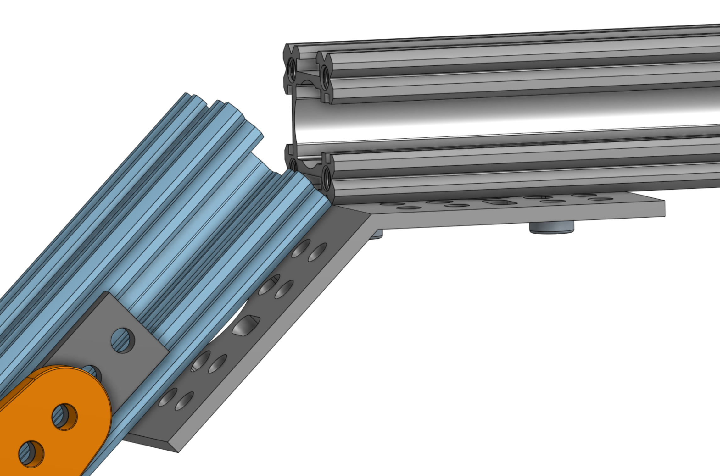
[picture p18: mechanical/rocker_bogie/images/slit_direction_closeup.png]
|   |

### Creating the rocker-bogie joint

First, gather the parts you'll need for the joint that connects the rocker to the bogie.

| Joint Parts |
| ---------------------------------------------- | 
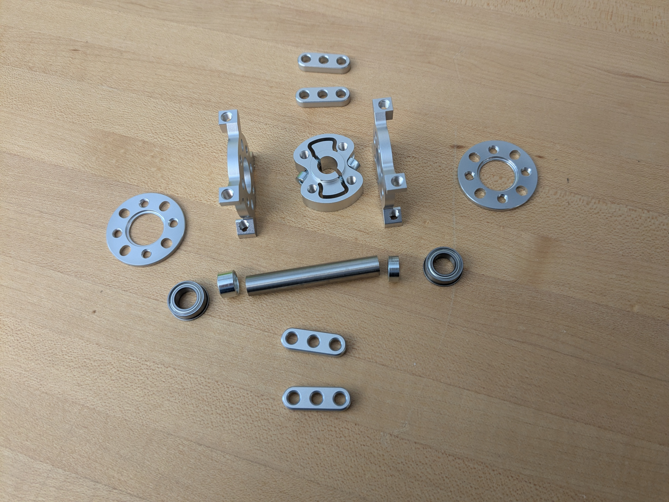
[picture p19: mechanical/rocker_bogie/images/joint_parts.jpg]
|   |

Assemble the joint following the steps below. Since the clamp in the middle isn't symmetric and protrudes on one side, two spacers of different lengths are used. You can see this in the top left image. You'll use spacer `1522-0010-0040` of length 4mm on the side of the clamp that has the protrusion, while on the other, flat side, you'll use spacer `1514-0010-0060` of length 6mm. This creates a tight assembly that prevents the joint from flexing from side to side.

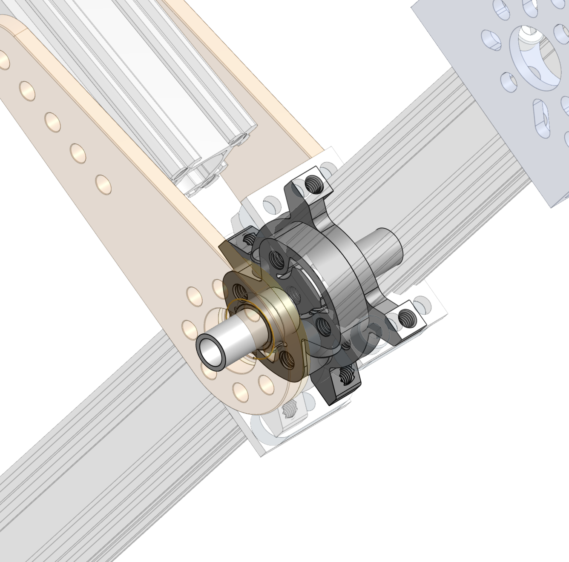
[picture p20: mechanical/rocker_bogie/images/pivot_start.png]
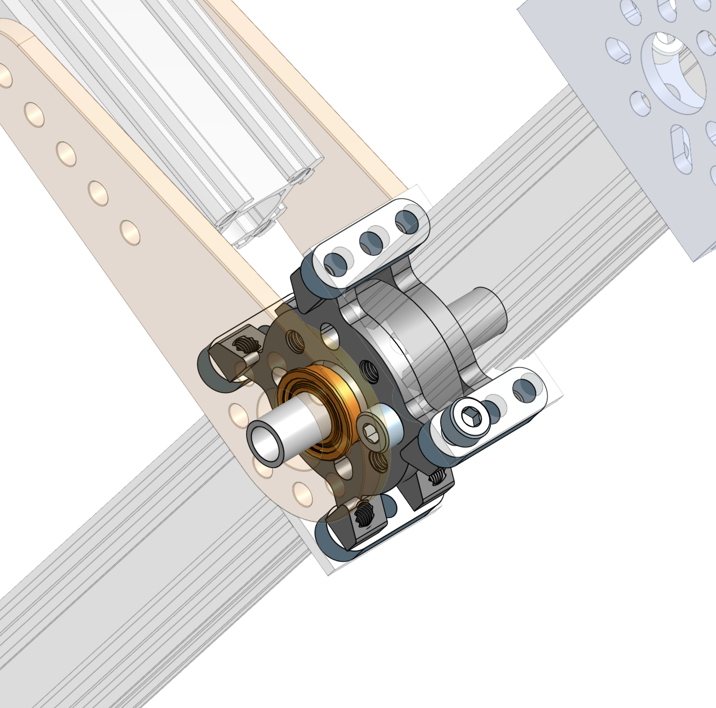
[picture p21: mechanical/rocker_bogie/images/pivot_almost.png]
|  |  |
| --- | --- |
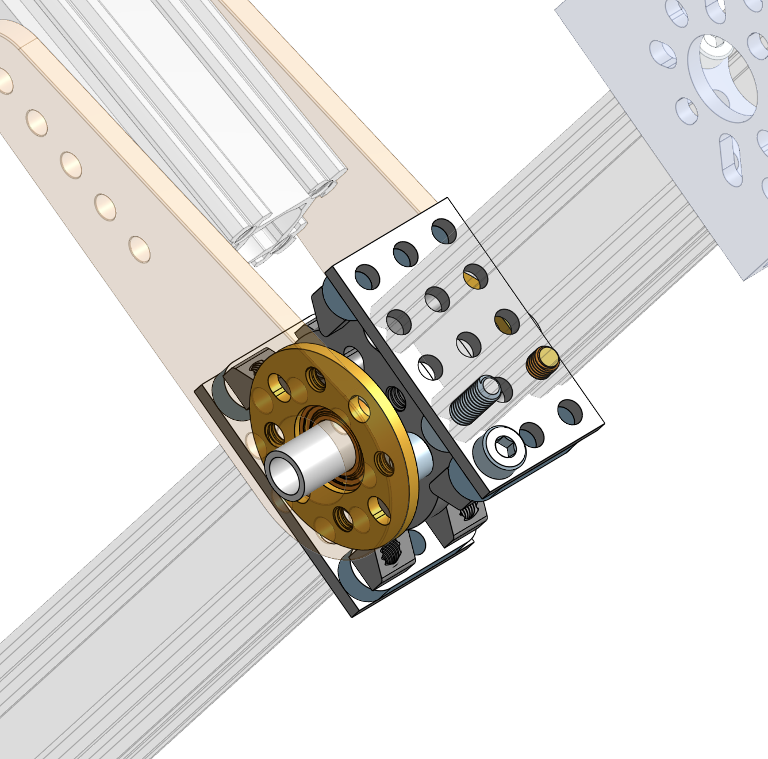
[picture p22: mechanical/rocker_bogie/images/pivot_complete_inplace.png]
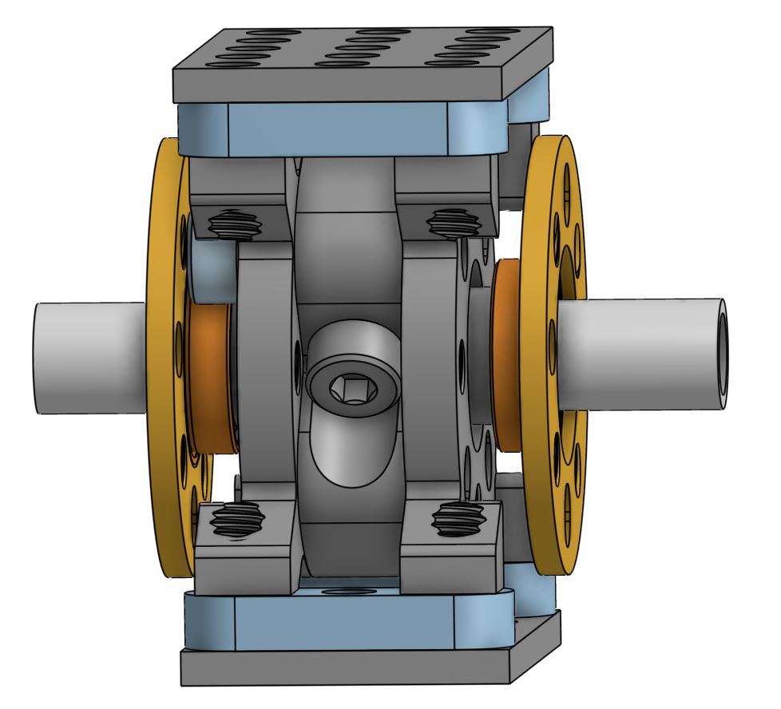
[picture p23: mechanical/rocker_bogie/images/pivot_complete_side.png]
|  |  |

Wait with the yellow and orange (ball bearing) parts. The bearing should first be inserted into the yellow hub.

> **Tip**: Use the OnShape model and navigate to the tab 'rocker-bogie' in the bottom to isolate this assembly. Then right click on various parts to temporarily hide them so you can see how the assembly works in 3D.

### Attach the control arms to the joint bearings

Referencing the orange and yellow parts in the image below, connect the hub (yellow) with the inserted bearing to the control arm using 8x socket or button M4 screws of length 12mm (or 10mm). Use washers so that the screw doesn't bury itself in the plastic control arm and to make sure the screw doesn't extend (much) on the insides of the hubs. When done, the bearing should not be able to fall out. Put these two assemblies aside for now. We'll connect each finished joint to the rockers in the following step.

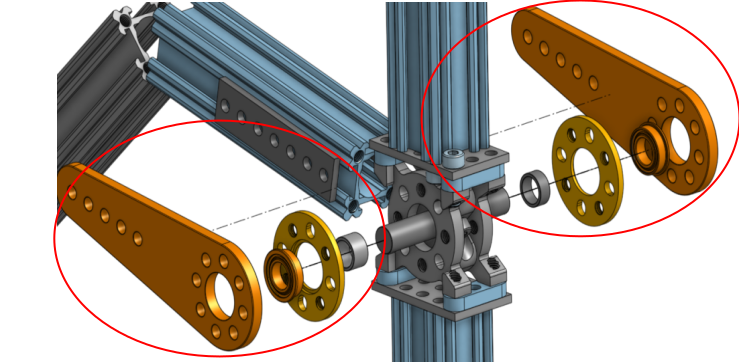
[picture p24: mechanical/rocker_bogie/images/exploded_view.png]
exploded view of the rocker-bogie joint


### Create the bogie

Attach a 3 hole x 5 hole plate `1116-0024-0040` to each of two length 96mm aluminum extrusions `1118-0024-0096` with 10mm button head screws as shown below.  Pay attention to direction of the slits for the cabling. You'll want the slit to face the short side of the plate.

Now attach the plate to a 3-hole flat beam, and to the bogie joint, with 10mm socket head screws.  You'll want the slits to face the top of the rover (the bogie arm) so you can route the cabling going to the front servo and motor inside of the channel.

| Plate on bogie shaft| Assembled bogie |
| --- | --- |
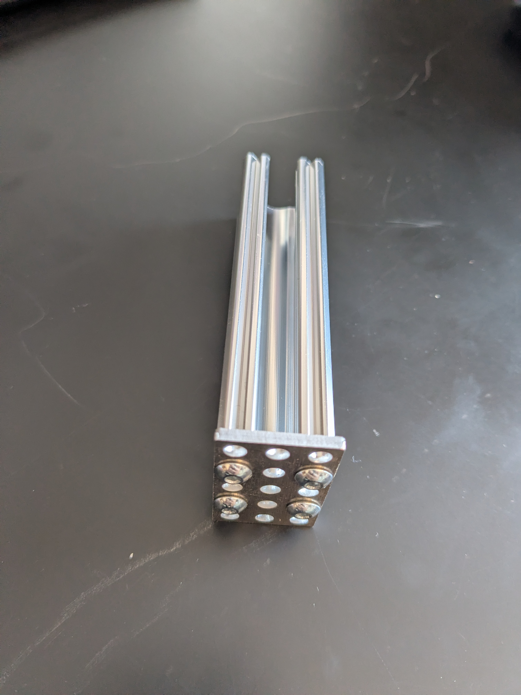
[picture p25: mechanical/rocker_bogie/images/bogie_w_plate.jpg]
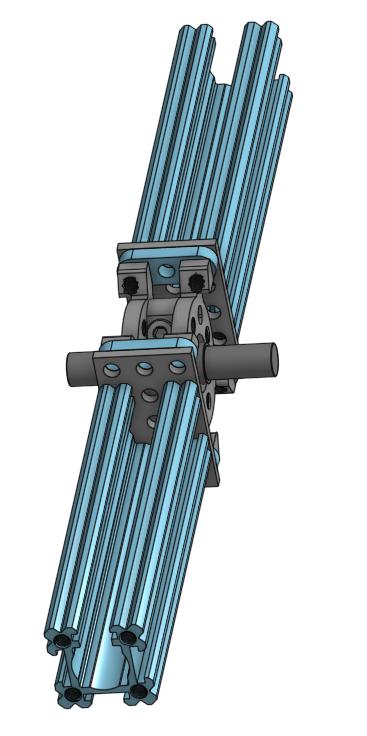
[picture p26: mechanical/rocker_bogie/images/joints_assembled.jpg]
|   |   |

#### Attach the front servo bracket and middle wheel bracket

Attach bracket `1111-0003-0001` to the top of the extruded shaft you just attached to the joint using three or four M4 screws.

Attach U channel `1120-0002-0072` to the bottom of the other extruded shaft you just attached to the joint using three or four M4 screws.

#### Route wiring through bogie

Install `2911-0014-0001` grommets at the top and bottom of the extruded aluminum goRail (inside the U channel on the bottom, and inside the servo bracket on the top), to protect your wires as they go around corners.

Run the servo wiring, including a 54cm extension, down from the front servo, which should be near the front servo bracket, down toward the joint.  

Run the 54cm encoder wires for the front corner motor from the front servo bracket toward the joint.

Run the middle motor power wiring from the U channel up toward the joint.

Run the middle motor encoder wires from the joint down to the U channel (or as shown in the picture, around it if you choose to notch your shafts), and encase in the protective sleeve.  

It should look like the last picture below, except that your servo block and servo won't be installed at this point.

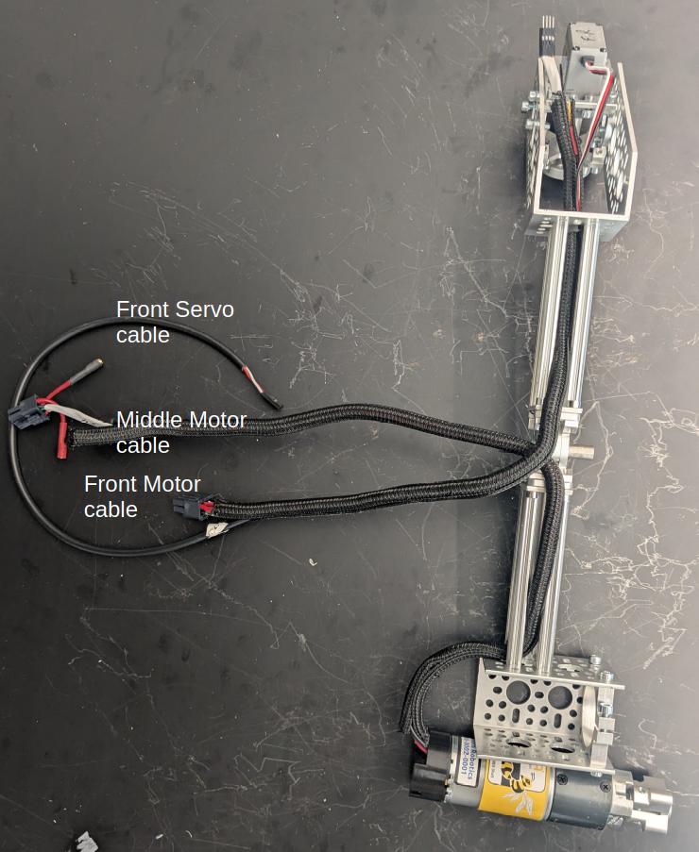
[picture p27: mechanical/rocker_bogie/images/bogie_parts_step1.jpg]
bogie parts step 1
| 
| --------- | 
| Bogie wiring installed.  |

#### Attach the front servo and servo block

Attach bracket `1111-0003-0001` to the extruded shaft you just attached to the joint using three or four M4 screws.

Then assemble the servo block to the servo motor. Insert the set screw that came with the servo inside the hollow shaft that fits onto the spline profile on the servo output, but don't tighten it yet as we'll have to readjust later when calibrating the corner motors. This screw prevents the corner assembly from falling off the rocker-bogie while driving. Finally, attach the servo motor and block to the front rocker-bogie bracket. The image below shows the resulting assembly.

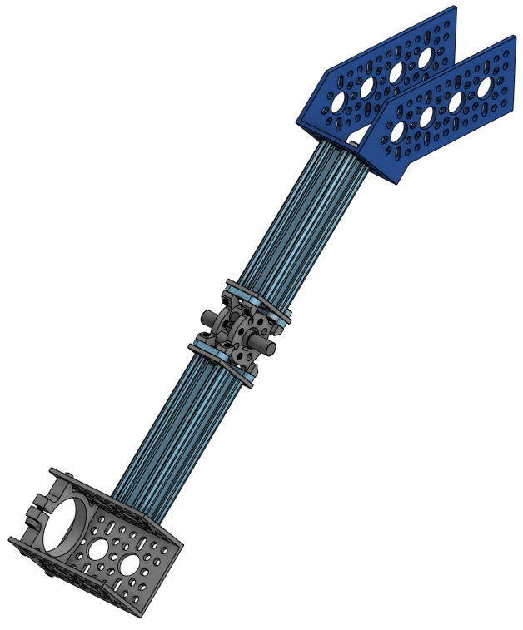
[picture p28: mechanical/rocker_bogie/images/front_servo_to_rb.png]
bracket and bogie joint
|  |
| --- |
| Bracket and Bogie Joint |

### Connect the control arms and rocker to the joint

Take one of the control arms (black plastic piece) with bearing and hub you made in an earlier step and attach the steel bracket, a [goRail Nut (5 Hole)](https://www.gobilda.com/gorail-nut-5-hole-2-pack/), and 7x socket screws with washers like in the image.

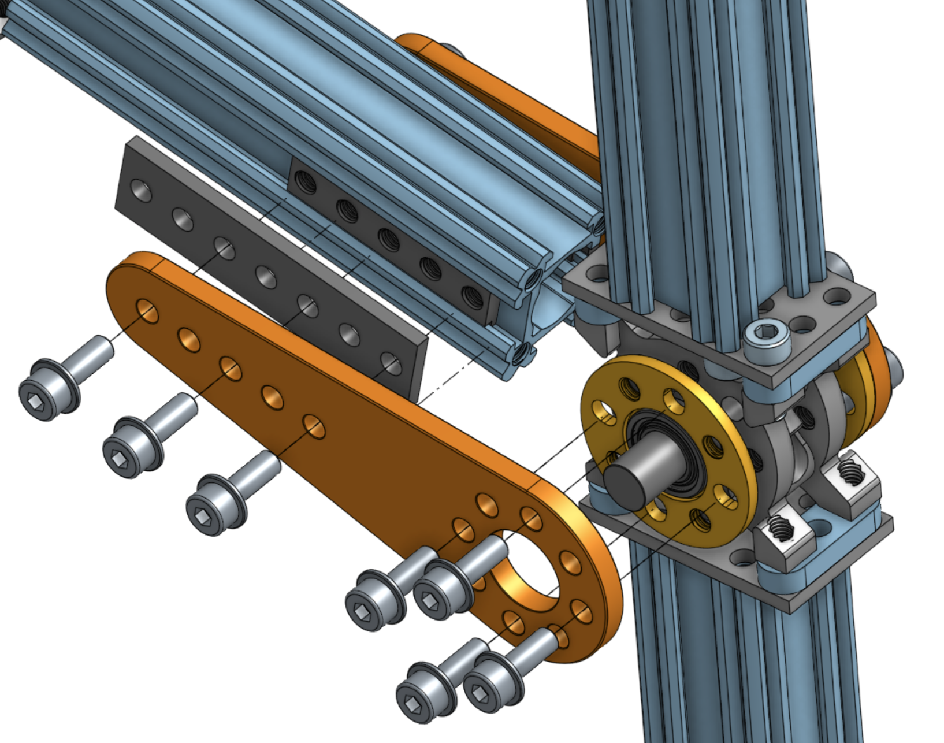
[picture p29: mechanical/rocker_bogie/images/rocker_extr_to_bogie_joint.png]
attaching the shaft from the rocker to the bogie joint


> [!NOTE]
> If you don't have the goRail nut (5 Hole) which was introduced July 2026, use three hurricane nuts instead. See the collapsed section below.

<details>

<summary>Instructions for when you don't have the goRail nuts</summary>

If the screws don't slide freely through the holes in the black control arm, drill the holes out to make sure the hurricane nuts rotate and lock in place in the rail.

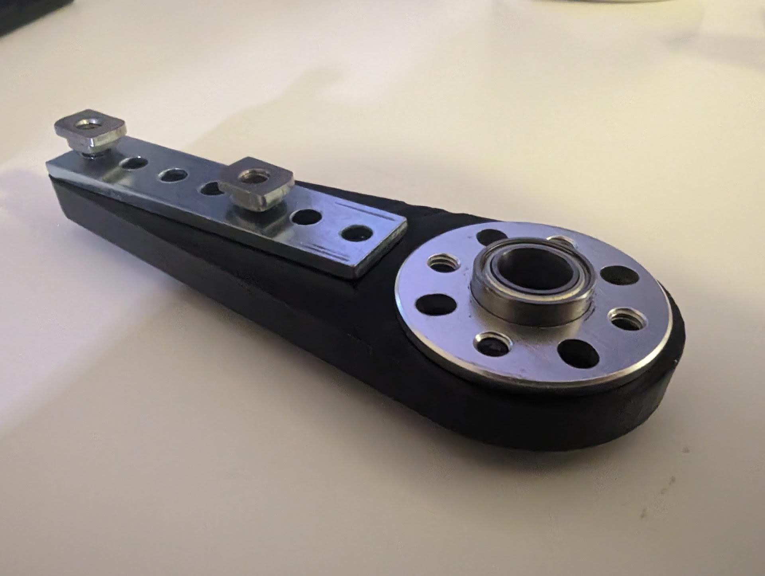
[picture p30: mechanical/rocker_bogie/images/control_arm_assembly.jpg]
picture of the control arm assembly


Unlike the image, use 3 hurricane nuts instead of 2. Connect the short part of the rocker (shaft `1110-0024-00096`) to the control arm on one side such that the hurricane nuts fit all the way in the channel.  Tighten such that you can still slide the control arm relative to the channel.  Make sure the slit faces the underside/back of the rover (you can also point the slit upwards or downwards if you prefer). The hurricane nuts have a tendency to seem stuck without actually getting their small 'wings' locked in the channel. If they're not properly inserted, the assembly will not have the required rigidity.

</details>
<br />

Repeat for the other control arm.

Route the wiring coming from the front, middle, and rear motors and servos through the slit (see left image below). It helps to temporarily keep the wiring in place with some tape as you attach the shaft to the bogie joint.

Flip the assembly over and repeat on the other side, making sure the setup is symmetric. Now tighten the screws all the way.

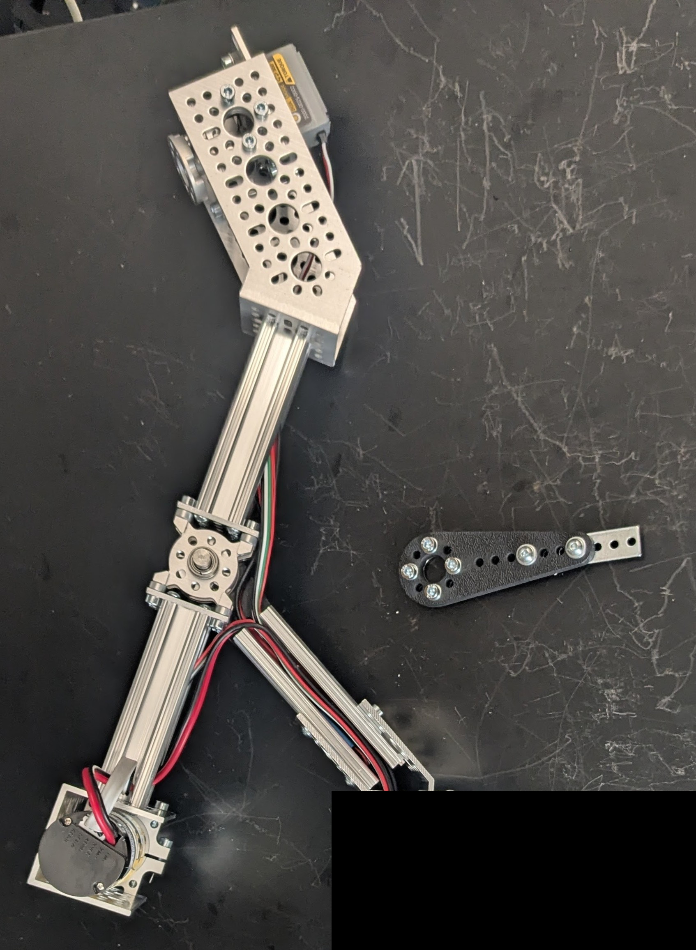
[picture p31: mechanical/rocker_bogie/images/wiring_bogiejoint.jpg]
wiring for bogie joint
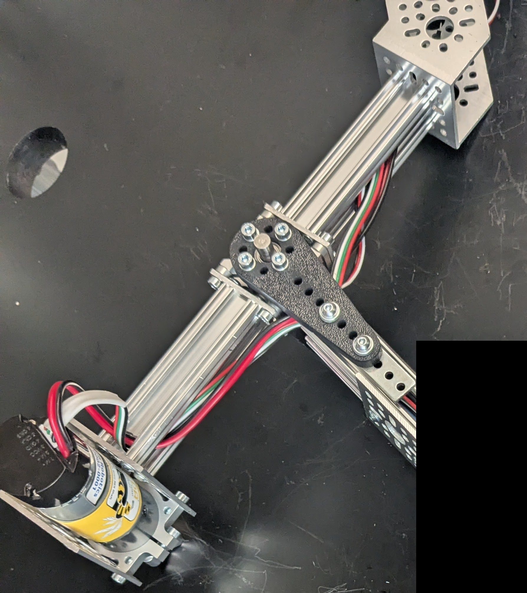
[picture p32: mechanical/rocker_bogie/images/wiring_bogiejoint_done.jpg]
wiring for bogie joint
|  |  |
| --- | --- |
| Running wiring through short shaft of rocker | Joint installed. |

> [!CAUTION]
> the OnShape model may represent the orientation of the slits incorrectly. In order to make the model nimble, the same rocker-bogie assembly is used on both sides of the rover which has the side-effect that the two assemblies aren't mirrored like they are supposed to be. Always stop to think about what you're building to avoid having to take things apart later.

### Assemble the back servo

Attach the 1-channel U bracket to the long extruded shaft `11118-0024-0288` using 3 or 4 M4 socket screws of length 10mm. Assemble another servo block as you did before. Insert this into the 1-channel bracket and attach using 6 button M4 screws of length 10mm (6mm or 8mm also works).

### Attach the front and back of the rocker-bogie

Use 4 hurricane nuts and the 45-degree bracket to connect the front and back of the rocker-bogie with 6mm M4 socket screws, as shown in the image below, on the underside of the rover. Avoid screws longer than 6mm, as they will hit the goRail before fully tightening.

bottom view

Flip the assembly over and attach the two brackets like in the picture below, using 4 more hurricane nuts and socket screws to secure the pieces to the rocker bogie aluminum extrusions. Then route all wires through the aluminum channel that will eventually slide into the rover body. The slit in the channel should orient in the direction where most of the cables enter it (flipped compared to the image below) but either direction works.

| assembly with wiring |
| --- |
| Wiring snugly fits inside the extruded aluminum channels, even with little or no sheathing. Only use this image as an idea of how the wiring should be routed, other parts of this image may not reflect the current state of the rocker-bogie at this stage in the process. |

Secure the channel to the rocker-bogie using 5 hurricane nuts (2 at the bottom) and socket screws, making sure the channel end sits flush to the other channels and the wiring isn't squeezed inbetween.

| top view | screws |
| --- | ---|

Repeat these steps for the other rocker-bogie, making sure it mirrors the first assembly. Once you're done, you're ready with these very important subassemblies!

complete assembly

> **Help improve documentation!** Please make an issue on Github when you spot something that's off or can be improved. Pull requests are even better! If you have a question, post in the #troubleshooting channel in our Slack group.

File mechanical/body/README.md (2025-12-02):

# Main Body Assembly
The body is the housing of all the electronics for the rover and acts as the attachment point for the differential pivot and the body axis that the rocker-bogies on either side connect to.

finished body
View of the body without PCB and with some of the body plates made transparent.

## Assemble the body frame
Gather the pieces from the [parts list for the body](../../parts_list/README.md/#parts-for-body-assembly).
* 4x 41 hole, 328mm square beams
* 5x 29 hole, 232mm square beams
* 8x 12 hole, 96mm square beams
* 26x M4x16 socket screws

### Bottom Frame
Connect 2x 29 hole and 2x 41 hole beams with M4x16 screws as shown.  Be sure to attach the cross beams 1 hole in on the long beams.
Insert 1 29 hole beam into hole #16, counting from the front of the rover. (TODO: Update image to move crossbar.)

body base

### Top Frame
Connect 2x 29 hole and 2x 41 hole beams with M4x16 screws as shown.  

body base

### Verticals
Connect 8x 12 hole beams along the long edges in holes #1, 17, 25, and 41 on both sides. (TODO: Update image to move crossbar.)

body verticals

## Assemble the bearing support structures that connect to the rocker-bogie

Make two of these and connect them to the sides of the body. They should be installed exactly in the middle, which means that you're going to connect each side to the 17th hole on the long 41-hole beams on the top and bottom of the body frame. Use the M4 16mm socket screws.  Use M4x12 screws on the end toward the outside of the rover and M4x8 screws on the end toward the center of the rover end.

The bearings have a flat side and a 'hollow' side. The hollow sides should both be pointing to the center of the rover side, as shown in the image.

Body Bearing Supports

Now, install the supports on the 6th hole from the top of the 12 hole beam, and the 5th hole from the bottom.  If it's a bit tight, loosen up the verticals until all the screws are started, then tighten all of them after.

bearing support structures installed

## Install the hinges for the top body plates
You will need the 20 or 22mm M4 standoffs, the 3x5 hole plate, the hinge assembly (assemble following the [instructions on GoBilda](https://www.gobilda.com/plastic-hinge-2-pack/), orientation matters).

 

First, attach the standoffs to the 3x5 plate with M4x8mm socket head screws

 

Then, attach the plate to the top front and top rear beam, leaving 4 holes to the outside of the plate.



Finally, attach the hinges to the standoffs, facing the flat part of the plastic to the outside and top as shown, with M4x8 screws



You will attach the body plate to the top part of the hinge in a later step.

 

## Make the differential pivot

The Differential Pivot helps to offload forces from one side of the rover to the other while climbing. The differential pivot is crucial in the rocker-bogie suspension system and is designed to help keep all 6 wheels on the ground at all times. It also allows a second attachment point for the body so that it does not freely rotate about the center axes that run through it and connects the two rocker-bogies.

### Gather the parts
You'll need the parts shown below.

parts

TODO: update image to show M4x6mm button screws instead of the M4x6mm socket head screws show here (and in the CAD)

Assemble the idler bearing hub following the [instructions on GoBilda](https://www.gobilda.com/idler-bearing-hub-32mm-od-16mm-height/).

Connect the block mount to the 7-hole linkage using M4x10mm button-head screws.  Connect the 20mm threaded rod to a steel ball linkage on each end to create two turnbuckles.

step 1

Connect the turnbuckle to the 7-hole bar linkages with an M4x20 socket head screw and lock nut, and to the second hole from the end of the U channel with an M4x16 button head screw and lock nut.  Repeat for other side.

step 2

Connect the differential pivot (the whole assembly) to the idler bearing hub with two M4x6 button-head screws 

step 3

Add 2x 29 hole, 232mm square beams in holes #28 and 30 from the front, on the longer 41 hole, 328mm beams, using M4x16mm socket head screws.  Mount the idler bearing hub to the crossbars with M4x12mm socket head screws as shown.

step 4

The differential pivot should be able to freely rotate around the body. We'll attach the side of the differential pivot to the rocker-bogies later.

## Install the laser cut body plates
Use M8x16 button head screws because of their lower profile along with nuts on the inside so the screws don't fall out while driving. 
If you've completed the PCB assemblies yet, you can attach them to the bottom body plate already, but you can also do this later.

body with top panels closed

body with top panels open

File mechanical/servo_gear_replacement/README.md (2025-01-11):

# Servo Motor Gear Replacement

In some cases, when the rover experiences a sudden, sharp impact (like a crash into a hard object), the corner servo motors can fail. More specifically, a central shaft holding two of the gears in place has been known to shear. When this happens, the gears will not mesh as smoothly, and, when forced, this can cause gear teeth to deform and break off completely from the output gear (see below).
 



This does not mean that the servo motor is useless. We can replace the gearset of the servo motor instead of purchasing a whole new motor. 

GoBilda sells [replacement gearsets](https://www.gobilda.com/servo-gear-set-for-2000-series-torque-servo-v3-0/) for their servo motors, as well as [replacement shafts](https://www.gobilda.com/replacement-shaft-for-2000-series-dual-mode-servo-gear-set-6-pack/). Be sure you have [grease](https://www.gobilda.com/super-lube-synthetic-grease-with-ptfe-clear-1ml-2-pack/) for the gears!

For the rest of this guide, references to "top", "bottom", "output gear", and "central shaft" are according to the following image:



## Diagnosing an issue

The first sign of an issue with the servo motors is when your corner wheels will not turn. This could be caused by either a loose electrical connection, or an issue in the gearset. 

In either case, power down the rover to allow the servos to free spin. Verify that the electrical connections are stable before resorting to motor disassembly.

If your connections are stable, then manually rotate the corner assembly. Rotate it to the extremes slowly, going through this motion a few times. If at any point the gears feel like they are binding or sticking, then there is an issue in the gearset. At this point, it is possible that just the shaft has sheared and the gears themselves are still intact. If you hear any rattling or the binding isn't momentary, then at least one gear has likely been damaged and needs to be replaced.

If the gears bind up, **do not force the rotation any further!!** This could cause gears to fail if they haven't already!

## Disassembling the Motor

1) You have a choice to either remove the motor from the corner assembly, or to disassemble the motor in-situ. In either case, first remove the screw connecting the servo hub-shaft to the servo output.

    

2) Remove the corner screws from the servo motor body.

    

3) Being careful not to remove the bottom portion of the body, which contains the servo circuit board, remove the body from the top portion of the servo.

    

    In the image, note how the shaft sections from the two central gears seem to have a ragged/jagged surface. This is the central shaft, which has sheared. 

    

    This closeup better shows both the sheared shaft, and the broken teeth on the output gear. In this case, both the output gear and the shaft need to be replaced

4) With a pair of tweezers or fine needlenose pliers, remove the gears from the motor housing. 

    

5) Remove the top bearing from the output gear and place it on the new output gear. This bearing is not on the output gear in the replacement gearset from GoBilda, so it's important not to lose the original.

    

    

    

6) Place the output gear first, as the top bearing may interfere with placing the output gear later.

    

7) While the other gears are out, remove the broken central shaft from both the top and bottom middle gears. Place the new central shaft in the top middle gear and replace in the case.

    

    

8) With the new shaft installed in the top middle gear, place the two top gears in the case again. Make sure all the gears are meshing correctly.

    

    

9) Place a healthy dose of grease in the gears to ensure smooth operation.

    

    

10) Reassemble the servo. Ensure that the black drive key is aligned with the keyway in the bottom of the output gear (see callouts in step 8).

    Close up the servo body and screw in the body screws.

    

11) If you unmounted the servo, remount the servo on the rover. 

12) Recalibrate corner servo.

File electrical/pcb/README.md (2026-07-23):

# Control Board Assembly, v2.0.3

The overall Control Board consists of a Motor Board with a Brain Board mounted on top. These are the instructions to assemble these two separate pcbs and mount them together as the unified control board.



This document goes through the process of assembling and testing the custom
Printed Circuit Boards for the project. 

Note that the images in these instructions are taken from an assembly of the v2.0.1 board. There are minimal differences between v2.0.1 and v2.0.3 - such that it wasn't worth doing another photoshoot for v2.0.3. Make sure to follow the written instructions when in doubt.

## Table of Contents
1. [Part References](#1-part-references)
2. [Schematic and Layout Documentation](#2-schematic-and-layout-documentation)
3. [Motor Board Assembly](#3-motor-board-assembly)
4. [Brain Board Assembly](#4-brain-board-assembly)
5. [Motor Board and Brain Board Mating](#5-motor-board-and-brain-board-mating)
6. [Testing the PCB and wiring for the Drive Motors](#6-testing-the-pcb-and-wiring-for-the-drive-motors)

## 1. Part References 

Check out the [BOM documents](control_board/BOM/v2.0.3)

All parts referenced in these instructions use the schematic "reference designator" from the silk screen on the pcbs. E.g. "C1", "J2", and "R28". You should look up the details of these parts within the [v2.0.3 BOM the board ref parts spreadsheet](control_board/BOM/v2.0.3/bom_v2.0.3_board_ref_parts.csv) or the [v2.0.3 BOM other parts spreadsheet](control_board/BOM/v2.0.3/bom_v2.0.3_other_parts.csv). This will tell you the unique ID of the part that we use for ordering from Digikey + elsewhere, and will also link to pictures of the part on the relevant website.

Generally these instructions have enough images to clearly show and identify the parts, but whenever in doubt the best thing to do is to look up the reference in the BOM spreadsheet.

## 2. Schematic and Layout Documentation

TODO: add versions for v2.0.3

There's documentation of both the schematics (how all the electrical parts logically connect to one another) and the layout (how the parts are physically placed on the boards) in the [control_board/documentation](control_board/documentation) directory

## 3. Motor Board Assembly

|    |
|:-:|
| Figure 3.0: front (left) and back (right) of motor board |

### 3.1 Attach standoffs

Attach standoffs to the bare board, for ease of future soldering work.

|   |
|:-:|
| Figure 3.1: Standoffs attached |

### 3.2 Solder on power headers and fuse holder

Solder on the XT30 headers for footprints J1, J3, J4, and J5, as well as the fuse holder F1.

Make sure to choose the proper XT30 header for the corresponding J footprint:
- J1: male
- J3: female
- J4: female
- J5: male
See the images to clarify which one is which.

The pins on the XT30 will be slightly smaller than the holes on the board - this is fine, just make sure to use a lot of solder to connect them so there's a good mechanical connection. The soldering should be fairly straightforward once you start. 

|  |
|:-:|
| Figure 3.2: Power headers + fuse holder footprints |

|  |
|:-:|
| Figure 3.3: Power headers + fuse holder attached |

|  |
|:-:|
| Figure 3.4: Power headers and fuse holder attached, zoomed out |

|  |
|:-:|
| Figure 3.5: Close up view of soldered footprints for headers |

### 3.3 Solder resistor R1 and power diode D1

Make sure to attach D1 in the correct orientation!

|  |
|:-:|
| Figure 3.6: Resistor R1 |

|  |
|:-:|
| Figure 3.7: Through hole leads for R1 and D1 |

|  |
|:-:|
| Figure 3.8: R1 and D1 attached |

### 3.4 Test the power connectors

Insert a fuse (part# B1) into the fuse holder (as shown in Figure 3.8 below)

Using the appropriate matching XT30 connectors, connect the power headers to a power supply (or your battery), the main external power switch (part# B9), and the multimeter (part# B10)

Use these diagrams to determine how to wire things together:

When testing with a power supply, provide 14.8V DC and current limit to 1.0A. Just to the left of the main fuse is a XT30 connector labeled "Switch" – this if for the main on/off toggle switch. The XT30 connectors labeled MM Load and MM DC connect to the multimeter box.

> [!Note]
> If you have already installed capacitors on the board, it is normal for power header J5 (MM Load) to briefly beep for less than a second when testing for continuity after soldering the power headers. This occurs because the capacitors momentarily charge. This behavior is expected and does not indicate a short circuit.

 |  |
|:-:|
| Figure 3.9: Power headers connected to the power supply, on/off toggle switch (out of view under the PCB) and multimeter box. |

After testing, make sure to disconnect the power supply.

|  |
|:-:|
| Figure 3.10: Wires connected to power headers |

|  |
|:-:|
| Figure 3.11: Power supply providing 14.8V DC and current limited to 1.0A |

Use a multimeter to test the voltage between test points T4 ("swt_out") and T2 ("Batt-"). This should read the same value as input from the power supply/battery (14.8V)

|  |
|:-:|
| Figure 3.12: Testing the voltage between T4 and T2 |

Also check the voltage shown by the multimeter. This should show the same voltage as well.

|  |
|:-:|
| Figure 3.13: Testing the power input to the multimeter |

### 3.5 Install the INA 260

:exclamation: Before continuing, make sure to disconnect the power supply from the previous step! You should not have the board powered on while installing components. :exclamation:

The INA260 daughter board is used for digital sensing of voltage and current, measurements that the raspberry pi can query over an I2C connection. Unfortunately, it can be hard to find these INA260 parts nowadays - if you can't find one you will need to bypass U1, because it is in the path of the battery positive side supply.

**Option 1: If you have an INA260 daughter board, you should install that in footprint U1 on the bottom side of the motor board.**

See [control_board/README.md](control_board/readme.md) for part numbers for inter-board pins and sockets.

1. Attach 8x1 female header sockets to the eight pads on the bottom side of the INA260 / U1 footprint, as seen in Figure 3.14.  This is sensing the current on the high side of the power, so PWR on the the Motor Board is connected to Vin+ on the INA260, and Vin- on the INA260 is connected to MMLOAD+, which connects to the main power bus of the rover.
2. Attach 3x1 female header socket (cut from a longer Nx1 header) to the two pads on the bottom side of the INA260 / U1 footprint, as seen in Figure 3.14. You'll need to manually remove the center pin, as there is no hole/pad on the brain board.

|  |
|:-:|
| Figure 3.14: Sockets on U1 footprint installed |

3. Attach 8x1 male header pins to the underside of the INA260, as seen in Figure 3.15
4. Remove the center pin from a 3x1 male header pins, and solder to the INA260.

|   |
|:-:|
| Figure 3.15: INA260 Pins installed |

5. Solder across pads A0 and A1 on the INA260 (to set it to use I2C Address 0x45)
6. Insert the INA260 male pins into the U1 female sockets, as shown in Figure 3.16
6. Optionally, install M2.5 x 12mm + 6mm standoffs between the motor board and the INA260.

|  |
|:-:|
| Figure 3.16: Headers on INA260 installed |

**Option 2: If you don't have one, you will need to bypass U1**

TODO: need to update this discussion of bypassing U1 once the layout has been updated

Install a 0 ohm resistor in footprint R30, on the top side of the board

### 3.6 Install 5V bus regulator

This is the power regulator for the 5V line, which powers all the motors.

Install 3 female headers for the daughter board, into U4. You will need a two 4x1's, and a 5x1.

|  |
|:-:|
| Figure 3.17: 5V regulator headers installed |

|  |
|:-:|
| Figure 3.18: 5V regulator installed |

### 3.7 Install 12V bus regulator U3

Solder a 5x1 female header to the U3 footprint, and attach an appropriately sized standoffs (I used an M3x10mm standoff)

|  |
|:-:|
| Figure 3.19: U3 footprint |

|  |
|:-:|
| Figure 3.20: 12v regulator installed |

|  |
|:-:|
| Figure 3.21: 12v regulator installed (2) |

### 3.8 Install 3.3V bus regulator U7 and decoupling capacitor C7

The 3.3V bus regulator is a linear voltage regulator and is physically much smaller - it comes in the same packaging as diode D1. Make sure to install the regulator in the correct direction as shown in figure 3.23.

Capacitor C7 is the decoupling capacitor for the 3.3v bus. Make sure to install C7 in the proper direction, as shown in figure 3.24. One side of the capacitor has negative polarity indicators on it, that should be installed opposite the "+" sign on the footprint.

|  |
|:-:|
| Figure 3.22: U7 footprint |

|  |
|:-:|
| Figure 3.23: 3.3v regulator installed in U7 |

|  |
|:-:|
| Figure 3.24: Capacitor C7 installed |

### 3.9 Install resistors R15, R24, and BJT transistor Q1

These form the circuit for the alert signal LED logic.

|  |
|:-:|
| Figure 3.25: R15, R24, and Q1 footprints |

|  |
|:-:|
| Figure 3.26: R15, R24, and Q1 installed |

### 3.10 Test all voltage lines

Test all the power buses/voltage lines using the test points on the far left side of the top side of the board (T7 through T12).

The silk screen right of each hole indicates what voltage each test point should be at.

- First, connect the power supply to your board and provide 14.8v (see step 3.4)
- then, use the multimeter to test the voltage at each test point

|  |
|:-:|
| Figure 3.27: testing the 3.3v bus|

|  |
|:-:|
| Figure 3.28: testing the 5v bus |

|  |
|:-:|
| Figure 3.29: testing the 12v bus |

|  |
|:-:|
| Figure 3.30: testing the Batt+ bus (positive lead from the battery) |

|  |
|:-:|
| Figure 3.31: testing the PWR bus (main board power plane, after battery protection circuitry ) |

### 3.11 Install PCA9685 daughter board in U2 footprint and capacitor C3

:exclamation: Before continuing, make sure to disconnect the power supply from the previous step! You should not have the board powered on while installing components. :exclamation:

The PCA9685 is a PWM signal source, which we use as our corner motor controller.

First you will need to install female headers on the motor board, for the PCA9685 daughter board to mate with. You'll need: 
- 6x1 female header
- 3x 2x4 female headers

You **may** use larger headers to fill all the holes in the U2 footprint, but it's not really necessary for the normal working configuration of the motor board. Attach these headers to the appropriate spots in the U2 footprint, as shown in figure 3.32.

|  |
|:-:|
| Figure 3.32: U2 with female headers installed |

You will need to attach male headers to the PCA9685 daughter board, as shown in figure 3.33. 

Also, 5v power is provided to the PCA9685 through the two holes at the top of the U2 header. You have a couple options for this.

**Option 1 - Wires**
To connect these, I soldered 2 small wire leads on the PCA9685 daughter board, and then soldered them on to the motor board once I installed the PCA9685.

**Option 2 - 1x1 Pins/Headers**
The V+ and GND on the PCA9685 don't exactly line up with the GND_motor and +5V_motor pins on the Motor board, but are close enough you can make them connect with two 1x1 pins on the PCA9685 and two 1x1 headers on the Motor board, as shown in figure 3.34.

|  |
|:-:|
| Figure 3.33: Male headers soldered onto PCA9685 daughter board |

|  |
|:-:|
| Figure 3.34: PCA9685 installed in motor board |

Finally install capicator C3 as shown in figure 3.36.

|  |
|:-:|
| Figure 3.35 : C3 installed |

### 3.12 Install resistor R5 and capacitor C1

These are aids for the INA260, and can be left out if the IN260 is not used

|  |
|:-:|
| Figure 3.36: PCA9685 installed in motor board |

### 3.13 Install J21, J20, and resistors R6,R7,R8,R9,R10

J21 is the interconnect header for the brain board, and J20 is a signal test header for the motor board

Use an 8x1 female header for J20.

|  |
|:-:|
| Figure 3.37: Components installed, as viewed from top of board |

### 3.14 Test INA260 installation

To test the INA260, you will follow https://learn.adafruit.com/adafruit-ina260-current-voltage-power-sensor-breakout/arduino, and connect an Arduino to GND, SCL, and SDA on J20.  You'll change the initalization step to
```
 if (!ina260.begin(0x45)) {
```
to account for the I2C bus address.  When you turn your power on, you should see something like this in the Arduino serial terminal:
```
Found INA260 chip
Current: 85.00 mA
Bus Voltage: 14456.25 mV
Power: 1230.00 mW
```

### 3.15 Install resistors R2,R3,R4

|  |
|:-:|
| Figure 3.38: Components installed, as viewed from top of board |

### 3.16 Install Roboclaw standoffs, headers, and capacitors

Now we'll add the parts for roboclaw footprints RC1, RC2, and RC3.

First, install standoffs for the 3 RC footprints, as shown an figure 3.33 and 3.34. 

Next, solder in the two female headers for each RC footprint. You'll need a 2x10 and a 5x1 for each RC. These should be soldered into the holes on the side of each RC footprint.

Finally, install the following capacitors for each RC footprint:
- RC1: capacitors C13,C15,C17,C20 (figure 3.40). Install on the top side of the board.
- RC2: capacitors C2,C4,C9,C10 (figure 3.39). Install on the underside of the board.
- RC3: capacitors C14,C16,C18,C21 (figure 3.40). Install on the top side of the board.

Technically, you can install the capacitors on either side of the board, but it makes for a cleaner presentation if you install them where their respective "C" labels are on the board.

|  |
|:-:|
| Figure 3.39: C2,C4,C9,C10 installed|

|  |
|:-:|
| Figure 3.40: C13,C15,C17,C20 and C14,C16,C18,C21 installed|

### 3.17 Install motor supply headers J16,J17,J18

Figure 3.41 shows how these should be installed. J16 on the top of the board is installed in the same way.

Make sure to orient the connector in the proper direction, as indicated in the images. 

|  |
|:-:|
| Figure 3.41: J17 and J18 installed, on bottom of board|

### 3.18 Install 3x Roboclaw boards in footprints RC1, RC2, RC3

First, wire the 6pos terminal block headers to the roboclaw boards, as indicated in figure 3.42.  Cut the wires to about 5cm and tin the ends.

Unless you have an older version of the PCB (v2.0.2 or earlier), wire the pins in the J16,J17,J18 headers directly to the pins on the corresponding side of the roboclaw - it is a direct 1-to-1 mapping all the way down, with no wires crossed. Use 16AWG wire (18AWG would also be fine)

Do this for all three roboclaws. 

|    |
|:-:|
| Figure 3.42: Wiring up the roboclaws |

Then install the 3 roboclaws in the RC1, RC2, and RC3 footprints. It doesn't matter which roboclaw goes in which footprint - we will later set unique addresses in software for each of them to communicate over the serial bus.

|  |
|:-:|
| Figure 3.43: Installing the roboclaw boards |

### 3.19 Install capacitors C5,C6

|  |
|:-:|
| Figure 3.44: Installing capacitors C5, C6|

### 3.20 Install corner servo header J19, and capacitor C19

Make sure to install C19 in the proper direction, as shown in figure 3.39. One side of the capacitor has negative polarity indicators on it, that should be installed opposite the "+" sign on the footprint.

|  |
|:-:|
| Figure 3.45: J19 and C19 installed (top of photo) |

### 3.21 Install LED array U5

Make sure to align the slightly "chipped"/beveled corner of the LED array with the beveled corner of the U5 footprint, to have proper LED polarity

|  |
|:-:|
| Figure 3.46: LED array U5 installed |

### 3.22 Install drive motor headers J8,J9,J10,J11,J13,J14

|  |
|:-:|
| Figure 3.47: Drive motor headers installed |

## 4. Brain Board Assembly

|    |
|:-:|
| Figure 4.0: front (left) and back (right) of brain board |

### 4.1 Install resistors

Install 3 sets of resistors:
- R11
- R25,R26,R27,R28,R29 
- R31,R32,R33,R34,R35

|  |
|:-:|
| Figure 4.1: Resistors installed |

### 4.2 Install switch SW1

Make sure to install the switch in the correct direction to match the footprint.

|  |
|:-:|
| Figure 4.2: Switch SW1 installed |

 ### 4.3 Install LED array U6 and various headers on top of board

Install these components:
- U6 LED array
- J22,J23 raspberry pi ribbon cable headers
- J25 3x4 male headers - "i2c breakout"
- J24 1x6 shrouded male header (white color) - "arduino comm"
- J30 8x1 male header - "signal test header"

Make sure to align the slightly "chipped"/beveled corner of the LED array with the beveled corner of the U6 footprint, to have proper LED polarity

Make sure to match the gaps on the sides of the J22 and J23 headers with the gaps indicated in the silk screen for these footprints.

Make sure to install J24 with the gap facing to the right of the top side of the board (as shown in figure 4.3)

|  |
|:-:|
| Figure 4.3: U6 and other headers installed  |

### 4.4 Install J26 header and capacitor C32 on back of board

Make sure to match the gaps on the side of the J26 header with the gap indicated in the silk screen for the footprint 

Ignore the resistors and figure 4.4 for the moment

|  |
|:-:|
| Figure 4.4: J26 (top) and C32 installed on back side of board |

Trim the leads of C32 before you continue.

### Install other breakouts on top of board

Finally, install J27,J28,J29 2x1 female headers in front of the leads of C32

### 4.5 Install ESTOP and Serial TXD/RXD LED logic circuit components

Here we install all the components used for the E_STOP, E_STOP2, E_STOP3 logic signals and LED indicators, and also the LED indicators for serial TXD/RXD activity.

Install all of these as indicated in figure 4.5:
- Q2, Q3, Q4, Q5, Q6 (BJT transistors) (**Polarity Warning!**)
- R18, R19, R20, R22, R23 (68 Ohms ±5% resistors)
- R16, R17, R36, R37, R38 (10k Ohms ±5% resistors)
- C33, C34 (10k pF ±10% 50V Ceramic Capacitors)
- D8, D9 (75V 300mA Diodes) (**Polarity Warning!**)
- Note: T13, T14, T15 should be left empty for probing.

 Note that polarity/installation direction matters for both the BJTs and the diodes (D8,D9). Make sure to match these with the image correctly! (note the black band on one side of the diodes faces to the right in figure 4.5)

|  |
|:-:|
| Figure 4.5: ESTOP and Serial TXD/RXD LED logic components installed  |

### 4.6 Mount the Raspberry Pi board

Using appropriate standoffs (M3x6mm+6mm works well, if a bit tight in the Raspberry Pi 5 mounting holes), attach the raspberry pi to the top of the brain board, as shown in figure 4.6.  Attach the ribbon cable from the GPIO on the Pi to J22.

|   |
|:-:|
| Figure 4.6: RPi mounted on the brain board  |

__Important Note if you are using a Raspberry Pi 5:__
The Raspberry Pi (RPi) 5 has different power requirements than previous RPi generations. The two 5v lines attached to the RPi via the ribbon cable are not to enough to adequately power the RPi 5, especially if attaching any peripherals, like a camera. Until further revisions are done to the PCB, it is recommeded to power the RPi 5 through a USB C connector. You can cut a USB C cable and identify the V+ and Ground lines using a digital multimeter, then solder those lines to the 5v and Gnd test connection points on the motorboard. You can then plug the USB C connector into the RPi 5 to power it.  You can also order USB-C cables with PWR/GND broken out already (see [Extra Parts List](../../parts_list/extra_parts.md))

## 5. Motor Board and Brain Board Mating

Using appropriate standoffs, attach the brain board to the top of the motor board, as shown in figure 5.0

TODO: identify the parts for the standoffs

|   |
|:-:|
| Figure 4.7: Mating the brain board to the motor board  |

And now you're done with the assembly! Finally, we'll move on to testing and configuration.

|    |
|:-:|
| Figure 4.8: Completed control board  |

## 6. Testing the PCB and wiring for the drive motors

Before we insert the wiring and PCBs into the mechanical assemblies, we'll test and configure the drive motors, wiring, and PCB. This allows us to fix these critical parts if something doesn't look right and allows us to move to running the software as soon as the rover is assembled.

For this you will need:

- wiring you made earlier in [wiring readme](../wiring/README.md)
- 6 drive motors
- completed PCBs
- a power source: a benchtop power supply or a charged battery
- wheel and [bore hub](https://www.gobilda.com/1310-series-hyper-hub-8mm-rex-bore/)

Secure the PCB assembly so it doesn't fall or move while it's on. You can attach it to the bottom body plate already. Avoid contact with any surfaces that can generate high-voltage sparks like carpets as that can destroy the electrical components.

Arrange the drive motors around the PCB and connect them using the wiring. Since we'll be calibrating them, make sure you connect the right motors to the right PCB receptacles. It helps to mark them using a sticky note or marker. The silk screen lettering should help here.

Connect a power source to your board as you did before. Verify that the roboclaws all receive power. A green light should be on on each roboclaw.

### 6.1 RoboClaw Testing and Verification

In this section you will be going one by one and and testing the operation of the RoboClaw Motor controllers. You will be doing this by using the GUI provided by the manufacturer of the motor controllers. The GUI can be found at [the BasicMicro website](https://www.basicmicro.com/downloads), under general downloads, then BasicMicro Motion Studio.

You'll also need the `USB RoboClaw Windows Driver` from the RoboClaw General Downloads section of the page. This should be installed before you run the Motion Studio.

To use the GUI, insert a USB to Micro USB cable from your computer to the motor controller you are going to be testing. In the Basic Motion GUI you should see an available device appear. It might require an update to proceed. Install the latest firmware update and then connect to the device.

Verify that all status lights are green and that the following values are shown at the top:

Temperature1: ~30
M1/M2 Amps: 0.00
M1/M2 Encoder: 0
M1/M2 Speed: 0
Main Battery: Between 11.5-16.7V
Logic Battery: 5V
Model: 2x7a

#### 6.2 Configuring general settings

The addresses for each Roboclaw unit by default are `128` which we want to change such that the Raspberry Pi can distinguish between Roboclaws and thus motors. We'll leave Roboclaw 1 at 128 and set Roboclaw 2 and 3 to 129 and 130 respectively.

In the `General Settings` tab:

- under `Setup`, set `Control Mode` to `Packet Serial`
- Enable the `Multi-Unit` mode flag
- Under `Serial`, set the `Packet Serial Address` to either 128, 129, or 130 depending on which roboclaw is plugged in
- set the `Baudrate` to `115200`
- Under `I/O`, make sure `Encoder 1 Mode` and `Encoder 2 Mode` are both set to `Quadrature`
- Under `Battery`, set `Max Main Battery` to `18.5V` and `Min Main Battery` to `11.5V`

Next, we'll check the correct direction and calibrate velocity before we repeat the process for the other roboclaws and motors.

#### 6.3 Prepare PWM signal

Click on the PWM tab. We will now send a PWM signal to the motor and test that connections are all made correctly to the motor and encoder. Start by selecting the `Enable Space Bar Stop All` button in the bottom left which allows you to set velocity to zero when you hit the space bar.

#### 6.4 Vary PWM signal

Slowly move the slider bar for the corresponding motor output channel. Verify that the right motor is spinning and that the encoder value is also changing.

- If there is no movement, the motors aren't getting current through the MA and MB wires. Check your wiring and look for red status lights within the Motion Studio GUI to troubleshoot.
- If the motor spins but the encoder value for that same motor/channel (M1 or M2) isn't changing, there likely is an issue with your encoder cabling. Use a multi-meter to verify connectivity.
- If all your connections are correct, you may have to test your solder contact between the components on the board itself.

> **Note**: When troubleshooting electrical connections, always remove power to the PCB to prevent shorting and injury.
Switch direction of the slide bar and verify that it spins the other direction and the encoder value does the opposite of previous as well.

Once you've verified this, we'll focus on the direction. We want the motor to spin as in the diagram below when we send a positive PWM:

motor direction diagram

For both motors check that the direction matches the diagram. If it doesn't, for that motor in the `General Settings` tab, select `M1 Reverse`. Check again to verify it matches. Now verify that the encoder value increases when you send a positive PWM for each motor. If it doesn't, select the `invert` checkbox in `General Settings` and verify again.

#### 6.5 Calibrate Velocity Settings

Click on the Velocity Settings tab. Here we will tune the velocity settings of the motor; these can only be done after setting the PWM direction in the previous step so ensure that those are done first. Furthermore, to get a precise calibration the wheels should be attached to the motors as they add some inertia to the system. Reference the [wheel assembly](../../mechanical/wheel_assembly/) instructions to see how to attach the wheels to the motor.

While the individual parameters can be tuned to precise values, for an initial/minimum setup we can use the Autotune feature. To do this first make sure your motor and wheel can freely spin (i.e. elevated off the ground and not in contact with anything). Then, select `Tune M1` under `Autotune`. The motor will rock back and forth several times slowly and quickly. Once the motor stops, the tuning is complete. Do the same for the second motor by selecting `Tune M2`. The velocity calibration is now complete.

The individual PID values can also be tuned manually after autotuning to tweak the motor performance. Roboclaw has an overview of all of the [velocity settings here](https://resources.basicmicro.com/velocity-settings-in-motion-studio/).

> **Important**: Make sure to save these settings to each Roboclaw's non-volatile memory by clicking on the `Device` menu > `Write Settings`.
Repeat starting from Section [6.1](#61-roboclaw-testing-and-verification) for the other two roboclaws.

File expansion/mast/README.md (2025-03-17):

# Mast Expansion

A mast can be added to the rover to house a camera, light, screen, environmental sensors or other components. 

This section describes how to build the pan and tilt mast seen below. Before you get too far along it is recommended to attach two servos to the PCA board and write some basic code that confirms you can control them. This build information covers the mechanical parts of the build, installing the sensors and the code to integrate them is beyond the scope of these instructions.

scout mast

### Materials List
#### Mast Structure
The following materials are needed to build the main structure of the mast (as seen above). All parts were purchased from gobilda.com. The "head" of the mast is covered further down.
- torque servo (2000-0025-0002) x 2
- servo block (3217-2701-2501) x 2
- 72mm length goTube (4103-0032-0072) x 1
- steel angle bracket (1142-0001-0001) x 1
- 1 pack dual block mount (1205-0001-0005) x 1
- U-channel (1 hole) (1120-0001-0048) x 1
- Various M4 screws
- servo wire extension sets (either make your own or buy on GoBilda)

#### Head
- 3D printed "box" for the head. (STL files for these 3D parts are in the 3d_models folder)
- sensors! you need to put something on the mast (the build above holds a camera and there is an extra hole for a light)

### Building It
Attach both of the servo blocks to the servos.

#### Underside
Remove the top plate of the rover body because you'll need to drill some holes in it. Drill a hole big enough for the servo hub shaft to fit through (exact size needed). In the example images this hole was placed 50mm back from the front and 50mm offset to the left (when facing the front of the rover). You'll also want to drill 4 holes to mount the block mount (would be good to know exact dimenions and locations for these holes).

Once the holes are drilled you can proceed with attaching the servo that controls the pan rotation to the _underside_ of the body top plate as seen in the image below. You'll attach the servo with its block to the the block mounts and the block mounts to the top plate of the body.

scout mast
_Underside of the top plate of the rover body. Red arrow points to one of the mount blocks. The other mount block is on the other side but not visible in this picture_

#### Topside
Attach the goTube to the servo hub shaft from the top. Using a long hex driver down through the center of the goTube, attach this unit to the servo.

scout mast
_Close up image showing goTube attached to servo hub, which is attached to the servo hidden underneath the top plate_.

Attach the second servo to the 1-hole U-Channel. Place the U-channel so that "U" is facing up. Attach this assembled part to the top of the goTube (the U-channel attached to the goTube is just visible in the image above). Attach the angle bracket to this second servo hub shaft – this will control the tilt of the head.

3D print the head and attach to the angle bracket.

Re-assemble the top plate to the rover body.

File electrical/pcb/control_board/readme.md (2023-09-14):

# Notes on the schematic (Control Board.sch)
    
- for library part ED2989-ND-USB, made VCC and GND passive because these are _alternative_ ways to power the +5V bus, and the electrical rules check-in kicad doesn't allow multiple power output sources for the same bus. Normally this bus is powered by the battery and voltage regulators.
- have to use a PWR_FLAG on the +BATT bus because this power net is not output from the battery directly, it's only available after a series of passive components (diode, fuse)
- also, doesn't really make sense to mark the battery connector ground pin as a "power output", so use PWR_FLAG for GND bus as well
- the 3.3v bus is not actaully powered; RPi's get power on the 5v bus
- We need separate power buses on the two boards, thus we created different power port symbols (e.g. the little triangle that says "GND")
    - the ports on the motor board are post-fixed "\_motor"
    - the ports on the brain board are post-fixed "\_brain"
    - We need different power ports because they function as a "global label" that can be seen across all sheets in a single schematic. So it's important to have different names. 
    - Note it's different for "net labels" - those are local in scope, to the given sheet
    - see https://forum.kicad.info/t/understanding-power-port-components/8945/14 for more background

# Important things to keep in mind when updating schematics

- make sure you're being cleanly about updating symbols in the schematic
    - you should update them in the JPL_Robotics_Lib.lib file, then pull those changes into the local schematic file in kicad
- if kicad creates "cache" or "rescue" libarary files, think before committing those to git. 
    - cache files _should_ be okay, but that's unclear. Ask someone before adding those to git versioning.
    - rescue files _should not_ be commited - but that's also unclear. Ask someone before adding those to git versioning.
- Reference Designators
    - it's important to retain the same reference designators (e.g. J12, U1, C3, etc) when revving the PCB - a lot of the discussion in the open source rover forums have referenced components by the reference designator, so that's a useful well-known name.
    - whenever annotating reference designators in kicad (with `Annotate Schematic...` ), make sure to check `keep existing annotations`
    - of course, if new components are added to the PCB schematic, these will need new completely designators. It's fine to use auto numbering for these.
    - in the worst case, you can always go into the .sch file and fix things by hand in a text editor

# Components

## LM358

- Why do we use these?
    - for buffering the raw encoder signals
    - [voltage follower layout](https://www.allaboutcircuits.com/video-tutorials/op-amp-applications-voltage-follower)
- [datasheet](https://www.ti.com/lit/ds/symlink/lm358.pdf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)
    - see table 6-1 for pin functions

## Roboclaw

- [Datasheet](https://downloads.basicmicro.com/docs/roboclaw_datasheet_2x30A.pdf](https://downloads.basicmicro.com/docs/roboclaw_datasheet_2x30A.pdf)
    - see page 5 and 6
- Pins
    - We don't use the encoder power (+/-, "PWR1/2" in the jpl robotics library) connections on the roboclaw pin header because we supply this via the screw terminals
    
## Raspberry Pi

- [Datasheet](https://www.raspberrypi.org/documentation/hardware/raspberrypi/bcm2711/rpi_DATA_2711_1p0_preliminary.pdf)
- For EEPROM ID SD and SC
    - See page 9 of the datasheet
    - SD is i2c clock (so this pin is set to output)
    - SD is i2c data (so this pin is set to bi-directional)

## Voltage regulators

- 12V
    - [Datasheet](https://www.pololu.com/product/2855)
- 5V
    - [Datasheet](https://www.pololu.com/product/2851)

## Inter-board connectors

- Male
    - PEC10DAAN
    - [Digikey](https://www.digikey.com/en/products/detail/PEC10DAAN/S2012E-10-ND/860601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)
    - [Summary drawing](https://drawings-pdf.s3.amazonaws.com/C10419.pdf)
- Female
    - PPTC102LFBN-RC
    - [Digikey](https://www.digikey.com/en/products/detail/PPTC102LFBN-RC/S7078-ND/810216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)
    - [Summary drawing](https://drawings-pdf.s3.amazonaws.com/10492.pdf)

## Secondary E-stop (e_stop 2) header

- PPTC021LFBN-RC
- [Digikey](https://www.digikey.com/en/products/detail/PPTC021LFBN-RC/S7000-ND/810142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)
- [Summary drawing](https://drawings-pdf.s3.amazonaws.com/10492.pdf)

## Adafruit INA260 headers

- The ina260 
    - https://www.adafruit.com/product/4226#technical-details
    - [pin details](https://learn.adafruit.com/assets/77678)
- 8 pin header
    - PEC08SAAN
    - [Digikey](https://www.digikey.com/en/products/detail/PEC08SAAN/S1012E-08-ND/859161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)
    - [Summary drawing](https://drawings-pdf.s3.amazonaws.com/C10436.pdf)
    - Don't need to connect vbus because we're doing high side sensing
- 2 pin header
    - PEC02SAAN
    - [Digikey](https://www.digikey.com/en/products/detail/sullins-connector-solutions/PEC02SAAN/859155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)
    - note! This header is actually 0.1" pitch, but we need 0.2" pitch. So the builder will have to go in and manually cut the pins apart. Shouldn't be too hard though.
    - for this reason, using a custom footprint with 0.2" spacing

## Adafruit 16-Channel Servo Driver

- 6 pin header
    - PPTC061LFBN-RC
    - [Digikey](https://www.digikey.com/en/products/detail/sullins-connector-solutions/PPTC061LFBN-RC/810145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)
- Motor output headers
    - PPTC041LFBN-RC
    - [Digikey](https://www.digikey.com/en/products/detail/PPTC041LFBN-RC/S7002-ND/810144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)
    - 3 of them for each section of 4 output channels on the servo driver board
- note that we don't need to connect the two pin power header, because we aren't routing power through the servo controller board, we're exclusively providing it through the control board

## Corner servo motor connectors

- 3 pin header
    - [Digikey](https://www.digikey.com/en/products/detail/PPTC031LFBN-RC/S7001-ND/810143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)

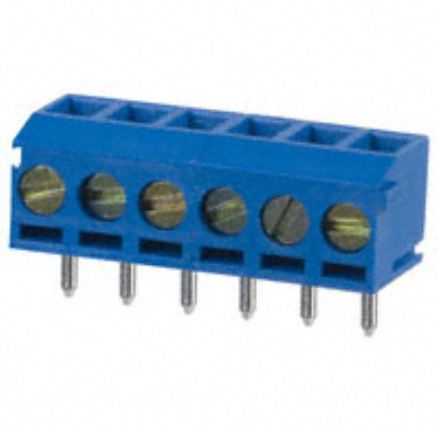
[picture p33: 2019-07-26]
images/components/electronics/E4.png

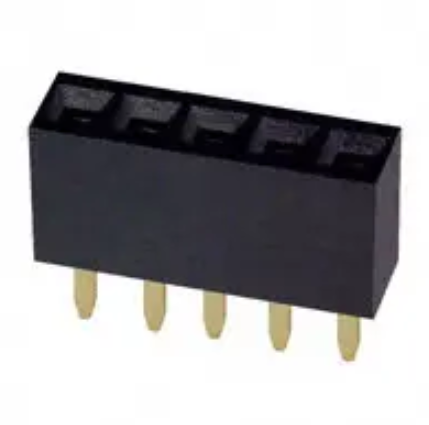
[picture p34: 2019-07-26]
images/components/electronics/E6.png

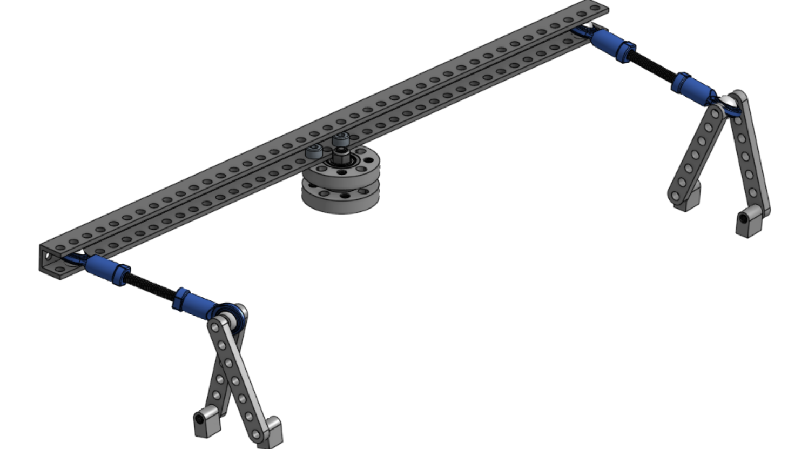
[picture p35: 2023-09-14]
mechanical/body/images/diff_pivot.png

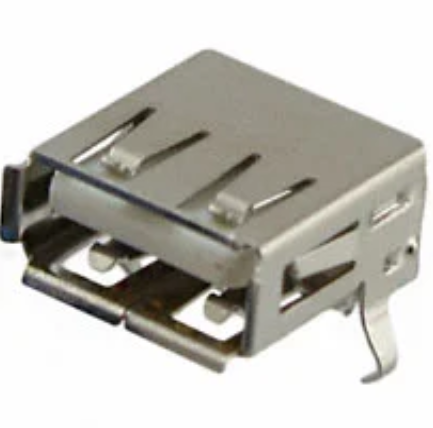
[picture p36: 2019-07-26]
images/components/electronics/E34.png

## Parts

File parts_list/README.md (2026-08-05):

# Parts list

This file was autogenerated from the [mechanical parts list](parts_list.csv) and [digikey BOM](digikey_bom.csv)
and should consist of the same parts, just presented in a more readable format. The Digikey csv file can be uploaded
to Digikey.com directly to create a shopping cart.
Before you place an order, please double check that you have all parts in the right quantities.

The total cost comes out to be **$1421.18** without the GoBilda educational discount (15%) and excluding shipping. **note**: GoBilda may change its pricing without notice.

## Parts for drive wheel assembly

| short name | link | cost per part | total # req | total cost |
|---|---|---|---|---|
| wheel | [Wasteland Wheel (144mm Diameter, 52mm Width)](https://www.gobilda.com/wasteland-wheel-144mm-diameter-52mm-width/) | $24.99 | 6 | $149.94 |
| clamping mount | [1401 Series 2-Side, 2-Post Clamping Mount (43mm Width, 36mm Bore) - goBILDA](https://www.gobilda.com/1401-series-2-side-2-post-clamping-mount-43mm-width-36mm-bore/) | $6.99 | 6 | $41.94 |
| motor | [5203 Series Yellow Jacket Planetary Gear Motor (26.9:1 Ratio, 24mm Length 8mm REX™ Shaft, 223 RPM, 3.3 - 5V Encoder)](https://www.gobilda.com/5203-series-yellow-jacket-planetary-gear-motor-26-9-1-ratio-24mm-length-8mm-rex-shaft-223-rpm-3-3-5v-encoder/) | $42.99 | 6 | $257.94 |
| REX bore hub | [1310 Series Hyper Hub (8mm REX™ Bore)](https://www.gobilda.com/1310-series-hyper-hub-8mm-rex-bore/) | $7.99 | 6 | $47.94 |
| 2 Hole U channel | [1120 Series U-Channel (2 Hole, 72mm Length) - goBILDA](https://www.gobilda.com/1120-series-u-channel-2-hole-72mm-length/) | $4.99 | 6 | $29.94 |

Cost to build these assemblies: $87.95 * 6 assemblies = $527.7

## Parts for corner assembly

| short name | link | cost per part | total # req | total cost |
|---|---|---|---|---|
| 144mm goRail | [1109 Series goRAIL (144mm Length) - goBILDA](https://www.gobilda.com/1109-series-gorail-144mm-length/) | $5.49 | 4 | $21.96 |
| 4 Hole U channel | [1121 Series Low-Side U-Channel (4 Hole, 120mm Length) - goBILDA](https://www.gobilda.com/1121-series-low-side-u-channel-4-hole-120mm-length/) | $5.99 | 4 | $23.96 |

Cost to build these assemblies: $11.48 * 4 assemblies = $45.92

## Parts for rocker bogie assembly

| short name | link | cost per part | total # req | total cost |
|---|---|---|---|---|
| 1hole uchannel | [1120 Series U-Channel (1 Hole, 48mm Length) - goBILDA](https://www.gobilda.com/1120-series-u-channel-1-hole-48mm-length/) | $3.69 | 2 | $7.38 |
| servoblock | [ServoBlock™ (Standard Size, 25 Tooth Spline, Hub Shaft) - goBILDA](https://www.gobilda.com/servoblock-standard-size-25-tooth-spline-hub-shaft/) | $29.99 | 4 | $119.96 |
| servo | [2000 Series Dual Mode Servo (25-2, Torque) - goBILDA](https://www.gobilda.com/2000-series-dual-mode-servo-25-2-torque/) | $31.99 | 4 | $127.96 |
| 8mm Sonic Hub | [1309 Series Sonic Hub (8mm Bore) - goBILDA](https://www.gobilda.com/1309-series-sonic-hub-8mm-bore/) | $6.99 | 2 | $13.98 |
| flanged bearing 2pack | [1611 Series Flanged Ball Bearing (8mm ID x 14mm OD, 5mm Thickness) - 2 Pack - goBILDA](https://www.gobilda.com/1611-series-flanged-ball-bearing-8mm-id-x-14mm-od-5mm-thickness-2-pack/) | $3.99 | 2 | $7.98 |
| joint pattern spacer | [1504 Series 32mm OD Pattern Spacer (2mm Length) - goBILDA](https://www.gobilda.com/1504-series-32mm-od-pattern-spacer-2mm-length/) | $1.99 | 4 | $7.96 |
| joint 8mm shaft | [2100 Series Stainless Steel Round Shaft (8mm Diameter, 50mm Length)](https://www.gobilda.com/2100-series-stainless-steel-round-shaft-8mm-diameter-50mm-length/) | $1.49 | 2 | $2.98 |
| joint 3hole flat beam 2pack | [1102 Series Flat Beam (3 Hole, 24mm Length) - 2 Pack - goBILDA](https://www.gobilda.com/1102-series-flat-beam-3-hole-24mm-length-2-pack/) | $1.89 | 4 | $7.56 |
| joint pattern mount | [1221 Series 2-Side, 2-Post Pattern Mount (32-2) - goBILDA](https://www.gobilda.com/1221-series-2-side-2-post-pattern-mount-32-2/) | $4.99 | 4 | $19.96 |
| steel flat bracket | [1126 Series Steel Flat Bracket (1-1) - 2 Pack - goBILDA](https://www.gobilda.com/1126-series-steel-flat-bracket-1-1-2-pack/) | $2.49 | 2 | $4.98 |
| 3x5 grid plate | [1116 Series Grid Plate (3 x 5 Hole, 24 x 40mm) - goBILDA](https://www.gobilda.com/1116-series-grid-plate-3-x-5-hole-24-x-40mm/) | $1.29 | 4 | $5.16 |
| angle bracket | [1111 Series Angle Pattern Bracket (3-1) - goBILDA](https://www.gobilda.com/1111-series-angle-pattern-bracket-3-1/) | $5.99 | 2 | $11.98 |
| 96mm open goRail | [1118 Series Open goRAIL (96mm Length) - goBILDA](https://www.gobilda.com/1118-series-open-gorail-96mm-length/) | $3.39 | 6 | $20.34 |
| 288mm open goRail | [1118 Series Open goRAIL (288mm Length) - goBILDA](https://www.gobilda.com/1118-series-open-gorail-288mm-length/) | $5.89 | 2 | $11.78 |
| 45deg bracket | [1111 Series Angle Pattern Bracket (1-1) - goBILDA](https://www.gobilda.com/1111-series-angle-pattern-bracket-1-1/) | $2.99 | 4 | $11.96 |
| 90deg steel bracket 2pack | [1137 Series Steel Flat Grid Bracket (1-1) - 2 Pack - goBILDA](https://www.gobilda.com/1137-series-steel-flat-grid-bracket-1-1-2-pack/) | $3.49 | 1 | $3.49 |
| control arm | [Plastic Hub-Mount Control Arm (72mm Length) - goBILDA](https://www.gobilda.com/plastic-hub-mount-control-arm-72mm-length/) | $4.99 | 4 | $19.96 |
| 8mm ID Spacer (10mm OD, 6mm Length) | [1522 Series 8mm ID Spacer (10mm OD, 6mm Length) - 4 Pack - goBILDA](https://www.gobilda.com/1522-series-8mm-id-spacer-10mm-od-6mm-length-4-pack/) | $3.49 | 1 | $3.49 |
| 8mm ID Spacer (10mm OD, 4mm Length) | [1522 Series 8mm ID Spacer (10mm OD, 4mm Length) - 4 Pack - goBILDA](https://www.gobilda.com/1522-series-8mm-id-spacer-10mm-od-4mm-length-4-pack/) | $2.99 | 1 | $2.99 |
| goRAIL® Nut (5 Hole) - 2 Pack | [goRAIL® Nut (5 Hole) - 2 Pack - goBILDA](https://www.gobilda.com/gorail-nut-5-hole-2-pack/) | $5.99 | 2 | $11.98 |

Cost to build these assemblies: $211.91 * 2 assemblies = $423.83

## Parts for body assembly

| short name | link | cost per part | total # req | total cost |
|---|---|---|---|---|
| 120mm open goRail | [1118 Series Open goRAIL (120mm Length) - goBILDA](https://www.gobilda.com/1118-series-open-gorail-120mm-length/) | $4.99 | 2 | $9.98 |
| 2 Hole U channel | [1120 Series U-Channel (2 Hole, 72mm Length) - goBILDA](https://www.gobilda.com/1120-series-u-channel-2-hole-72mm-length/) | $4.99 | 2 | $9.98 |
| 32mm bearing | [1604 Series 2-Side, 2-Post Pillow Block (32mm Bore) - goBILDA](https://www.gobilda.com/1604-series-2-side-2-post-pillow-block-32mm-bore/) | $12.99 | 4 | $51.96 |
| 32mm 6mm spacer 2 pack | [1506 Series 32mm ID Spacer (36mm OD, 6mm Length) - 2 Pack - goBILDA](https://www.gobilda.com/1506-series-32mm-id-spacer-36mm-od-6mm-length-2-pack/) | $3.49 | 3 | $10.47 |
| 29 hole beam | [1106 Series Square Beam (29 Hole, 232mm Length) - goBILDA](https://www.gobilda.com/1106-series-square-beam-29-hole-232mm-length/) | $5.09 | 7 | $35.63 |
| 41 hole beam | [1106 Series Square Beam (41 Hole, 328mm Length) - goBILDA](https://www.gobilda.com/1106-series-square-beam-41-hole-328mm-length/) | $6.99 | 4 | $27.96 |
| 12 hole beam | [1106 Series Square Beam (12 Hole, 96mm Length) - goBILDA](https://www.gobilda.com/1106-series-square-beam-12-hole-96mm-length/) | $2.99 | 8 | $23.92 |
| 41 hole u-beam beam | [1101 Series U-Beam (41 Hole, 328mm Length) - goBILDA](https://www.gobilda.com/1101-series-u-beam-41-hole-328mm-length/) | $3.89 | 1 | $3.89 |
| 7 hole flat beam 2pack | [1102 Series Flat Beam (7 Hole, 56mm Length) - 2 Pack - goBILDA](https://www.gobilda.com/1102-series-flat-beam-7-hole-56mm-length-2-pack/) | $2.49 | 2 | $4.98 |
| dual block mount | [1205 Series Dual Block Mount (1-4) - 2 Pack - goBILDA](https://www.gobilda.com/1205-series-dual-block-mount-1-4-2-pack/) | $5.99 | 2 | $11.98 |
| 90deg threaded gusset 4pack | [1203 Series Block Mount (1-1) - 4 Pack - goBILDA](https://www.gobilda.com/1203-series-block-mount-1-1-4-pack/) | $4.99 | 1 | $4.99 |
| 50mm threaded rod | [2808 Series Stainless Steel Threaded Rod (M4 x 0.7mm, 50mm Length) - 2 Pack - goBILDA](https://www.gobilda.com/2808-series-stainless-steel-threaded-rod-m4-x-0-7mm-50mm-length-2-pack/) | $1.49 | 1 | $1.49 |
| ball linkage 2pack | [2913 Series Steel Ball Linkage (Female M4 x 0.7mm, 24.1mm Length) - 2 Pack - goBILDA](https://www.gobilda.com/2913-series-steel-ball-linkage-female-m4-x-0-7mm-24-1mm-length-2-pack/) | $4.99 | 2 | $9.98 |
| Idler Bearing Hub | [Idler Bearing-Hub (32mm OD, 16mm Height) - goBILDA](https://www.gobilda.com/idler-bearing-hub-32mm-od-16mm-height/) | $12.99 | 1 | $12.99 |
| plastic hinges | [Plastic Hinge - 2 Pack - goBILDA](https://www.gobilda.com/plastic-hinge-2-pack/) | $4.99 | 2 | $9.98 |
| 8mm standoffs | [1501 Series M4 x 0.7mm Standoff (6mm OD, 8mm Length) - 4 Pack](https://www.gobilda.com/1501-series-m4-x-0-7mm-standoff-6mm-od-8mm-length-4-pack/) | $2.49 | 2 | $4.98 |
| 22mm standoffs | [1501 Series M4 x 0.7mm Standoff (6mm OD, 22mm Length) - 4 Pack](https://www.gobilda.com/1501-series-m4-x-0-7mm-standoff-6mm-od-22mm-length-4-pack/) | $3.49 | 2 | $6.98 |
| plastic spacer | [1500 Series Plastic Spacer (6mm ID x 8mm OD, 1mm Thickness) - 12 Pack](https://www.gobilda.com/1500-series-plastic-spacer-6mm-id-x-8mm-od-1mm-thickness-12-pack/) | $2.79 | 1 | $2.79 |
| 3x5 grid plate | [1116 Series Grid Plate (3 x 5 Hole, 24 x 40mm)](https://www.gobilda.com/1116-series-grid-plate-3-x-5-hole-24-x-40mm/) | $1.29 | 4 | $5.16 |
| 2 hole flat beam | [1102 Series Flat Beam (2 Hole, 16mm Length) - 2 Pack](https://www.gobilda.com/1102-series-flat-beam-2-hole-16mm-length-2-pack/) | $1.79 | 2 | $3.58 |

Cost to build this assembly: $253.67

## Parts for general assembly

| short name | link | cost per part | total # req | total cost |
|---|---|---|---|---|
| hurricane nuts | [Hurricane Nut for goRAIL - 25 Pack - goBILDA](https://www.gobilda.com/hurricane-nut-for-gorail-25-pack/) | $9.99 | 1 | $9.99 |
| wire grommets | [Plastic Grommet (14-1) - 12 Pack - goBILDA](https://www.gobilda.com/plastic-grommet-14-1-12-pack/) | $1.99 | 1 | $1.99 |
| M4 washers | [Zinc Plates Steel Washer (M4 x 8mm OD) - 25 Pack - goBILDA](https://www.gobilda.com/2801-series-zinc-plated-steel-washer-4mm-id-x-8mm-od-25-pack/) | $1.99 | 1 | $1.99 |
| M4 nuts | [Zinc Plates Steel Hex Nut (M4 x 7) - 25 Pack - goBILDA](https://www.gobilda.com/2811-series-zinc-plated-steel-hex-nut-m4-x-0-7mm-7mm-hex-25-pack/) | $2.49 | 4 | $9.96 |
| M4 locknuts | [Zinc Plates Steel Locknut (M4 x 7) - 25 Pack - goBILDA](https://www.gobilda.com/2812-series-zinc-plated-steel-nylon-insert-locknut-m4-x-0-7mm-7mm-hex-25-pack/) | $2.99 | 1 | $2.99 |
| M4x6 button screws | [M4x6 Button Screw 25-pack](https://www.gobilda.com/2802-series-zinc-plated-steel-button-head-screw-m4-x-0-7mm-6mm-length-25-pack/) | $2.99 | 2 | $5.98 |
| M4x10 button screws | [M4x10 Button Screw 25-pack](https://www.gobilda.com/2802-series-zinc-plated-steel-button-head-screw-m4-x-0-7mm-10mm-length-25-pack/) | $3.39 | 3 | $10.17 |
| M4x16 button screws | [M4x16 Button Screw 25-pack](https://www.gobilda.com/2802-series-zinc-plated-steel-button-head-screw-m4-x-0-7mm-16mm-length-25-pack/) | $3.79 | 2 | $7.58 |
| M4x8 socket screws | [M4x8 Socket Screw 25-pack](https://www.gobilda.com/2800-series-zinc-plated-steel-socket-head-screw-m4-x-0-7mm-8mm-length-25-pack/) | $3.19 | 2 | $6.38 |
| M4x10 socket screws | [M4x10 Socket Screw 25-pack](https://www.gobilda.com/2800-series-zinc-plated-steel-socket-head-screw-m4-x-0-7mm-10mm-length-25-pack/) | $3.19 | 3 | $9.57 |
| M4x1２ socket screws | [M4x12 Socket Screw 25-pack](https://www.gobilda.com/2800-series-zinc-plated-steel-socket-head-screw-m4-x-0-7mm-12mm-length-25-pack/) | $3.19 | 1 | $3.19 |
| M4x16 socket screws | [M4x16 Socket Screw 25-pack](https://www.gobilda.com/2800-series-zinc-plated-steel-socket-head-screw-m4-x-0-7mm-16mm-length-25-pack/) | $3.19 | 2 | $6.38 |
| M4x20 socket screws | [M4x20 Socket Screw 25-pack](https://www.gobilda.com/2800-series-zinc-plated-steel-socket-head-screw-m4-x-0-7mm-20mm-length-25-pack/) | $3.09 | 1 | $3.09 |

Cost to build this assembly: $79.26

## Parts for electrical assembly

| short name | link | cost per part | total # req | total cost |
|---|---|---|---|---|
| A1: CAP CER 10000PF 50V X7R RADIAL | [399-9865-1-ND](https://www.digikey.com/en/products/result?keywords=399-9865-1-ND) | $0.164 | 20 | $3.28 |
| A2: CAP ALUM 100UF 20% 50V RADIAL | [399-18272-1-ND](https://www.digikey.com/en/products/result?keywords=399-18272-1-ND) | $0.248 | 10 | $2.48 |
| A3: CAP CER 0.1UF 50V X7R RADIAL | [399-14065-1-ND](https://www.digikey.com/en/products/result?keywords=399-14065-1-ND) | $0.211 | 10 | $2.11 |
| A4: CAP ALUM 10UF 20% 50V RADIAL | [399-ESK106M050AC3DACT-ND](https://www.digikey.com/en/products/result?keywords=399-ESK106M050AC3DACT-ND) | $0.162 | 10 | $1.62 |
| A5: DIODE SCHOTTKY 25V 10A TO220AC | [497-2738-5-ND](https://www.digikey.com/en/products/result?keywords=497-2738-5-ND) | $1.93 | 2 | $3.86 |
| A6: DIODE GEN PURP 75V 300MA DO35 | [1655-1N4148CT-ND](https://www.digikey.com/en/products/result?keywords=1655-1N4148CT-ND) | $0.108 | 10 | $1.08 |
| A7: FUSEHOLDER BLOCKS - PCB - CLIP C | [732-11376-ND](https://www.digikey.com/en/products/result?keywords=732-11376-ND) | $0.68 | 1 | $0.68 |
| A10: CONN HEADER VERT 12POS 2.54MM | [TSW-104-07-F-T-ND](https://www.digikey.com/en/products/result?keywords=TSW-104-07-F-T-ND) | $1.5 | 4 | $6.0 |
| A11: CONN HEADER VERT 8POS 2.54MM | [S1012E-08-ND](https://www.digikey.com/en/products/result?keywords=S1012E-08-ND) | $0.47 | 4 | $1.88 |
| A12: CONN HDR 20POS 0.1 TIN PCB | [S7078-ND](https://www.digikey.com/en/products/result?keywords=S7078-ND) | $1.3 | 1 | $1.3 |
| A13: CONN HEADER VERT 40POS 2.54MM | [S9175-ND](https://www.digikey.com/en/products/result?keywords=S9175-ND) | $0.73 | 2 | $1.46 |
| A14: CONN HEADER VERT 6POS 2MM | [455-1708-ND](https://www.digikey.com/en/products/result?keywords=455-1708-ND) | $0.36 | 2 | $0.72 |
| A16: CONN HEADER VERT 20POS 2.54MM | [WM6548-ND](https://www.digikey.com/en/products/result?keywords=WM6548-ND) | $2.52 | 1 | $2.52 |
| A17: CONN HDR 2POS 0.1 TIN PCB | [S7000-ND](https://www.digikey.com/en/products/result?keywords=S7000-ND) | $0.32 | 5 | $1.6 |
| A19: TERM BLK 2P SIDE ENT 5.08MM PCB | [ED2580-ND](https://www.digikey.com/en/products/result?keywords=ED2580-ND) | $0.73 | 2 | $1.46 |
| A20: CONN HEADER VERT 6POS 4.2MM | [1726750613-ND](https://www.digikey.com/en/products/result?keywords=1726750613-ND) | $2.27 | 6 | $13.62 |
| A21: TRANS PNP 40V 0.2A TO92-3 | [2N3906TAFSCT-ND](https://www.digikey.com/en/products/result?keywords=2N3906TAFSCT-ND) | $0.285 | 10 | $2.85 |
| A22: RES 100 OHM 5% 1/4W AXIAL | [CF14JT100RCT-ND](https://www.digikey.com/en/products/result?keywords=CF14JT100RCT-ND) | $0.056 | 10 | $0.56 |
| A23: RES 10K OHM 5% 1/4W AXIAL | [CF14JT10K0CT-ND](https://www.digikey.com/en/products/result?keywords=CF14JT10K0CT-ND) | $0.056 | 10 | $0.56 |
| A24: RES 4.7K OHM 5% 1/4W AXIAL | [CF14JT4K70CT-ND](https://www.digikey.com/en/products/result?keywords=CF14JT4K70CT-ND) | $0.0404 | 25 | $1.01 |
| A25: RES 0 OHM JUMPER 1/4W AXIAL | [CD14ZT0R00CT-ND](https://www.digikey.com/en/products/result?keywords=CD14ZT0R00CT-ND) | $0.079 | 10 | $0.79 |
| A26: RES 68 OHM 5% 1/8W AXIAL | [CF18JT68R0CT-ND](https://www.digikey.com/en/products/result?keywords=CF18JT68R0CT-ND) | $0.045 | 10 | $0.45 |
| A27: RES 82 OHM 5% 1/4W AXIAL | [CF14JT82R0CT-ND](https://www.digikey.com/en/products/result?keywords=CF14JT82R0CT-ND) | $0.056 | 10 | $0.56 |
| A28: RES 1K OHM 5% 1/4W AXIAL | [CF14JT1K00CT-ND](https://www.digikey.com/en/products/result?keywords=CF14JT1K00CT-ND) | $0.056 | 10 | $0.56 |
| A29: RES 680 OHM 5% 1/4W AXIAL | [CF14JT680RCT-ND](https://www.digikey.com/en/products/result?keywords=CF14JT680RCT-ND) | $0.056 | 10 | $0.56 |
| A30: RES 220 OHM 5% 1/4W AXIAL | [CF14JT220RCT-ND](https://www.digikey.com/en/products/result?keywords=CF14JT220RCT-ND) | $0.056 | 10 | $0.56 |
| A32: SWITCH SLIDE DIP SPDT 50MA 24V | [CT206124-ND](https://www.digikey.com/en/products/result?keywords=CT206124-ND) | $1.25 | 1 | $1.25 |
| A37: LED BAR GRAPH 10SEG 570NM GRN | [754-2186-ND](https://www.digikey.com/en/products/result?keywords=754-2186-ND) | $3.26 | 2 | $6.52 |
| A38: IC REG LINEAR 3.3V 750MA TO220-3 | [576-2235-ND](https://www.digikey.com/en/products/result?keywords=576-2235-ND) | $3.02 | 2 | $6.04 |
| B1: FUSE GLASS 10A 125VAC 5X20MM | [F3631-ND](https://www.digikey.com/en/products/result?keywords=F3631-ND) | $1.21 | 2 | $2.42 |
| B9: SWITCH TOGGLE ON-OFF-ON | [708-3060-ND](https://www.digikey.com/en/products/result?keywords=708-3060-ND) | $3.28 | 1 | $3.28 |
| B11: TERM BLOCK HDR 24POS VERT 5MM | [ED1682-24-ND](https://www.digikey.com/en/products/result?keywords=ED1682-24-ND) | $3.33 | 1 | $3.33 |
| A9: TERM BLOCK HDR 6POS VERT 3.5MM | [WM25701-ND](https://www.digikey.com/en/products/result?keywords=WM25701-ND) | $2.02 | 3 | $6.06 |
| B2: TERM BLOCK PLUG 6POS STR 3.5MM | [WM13033-ND](https://www.digikey.com/en/products/result?keywords=WM13033-ND) | $2.59 | 3 | $7.77 |

Cost to build this assembly: $90.8

## Extra Parts

These parts you may either already have, depend on where you're located for a good deal, depend on personal preference, or are optional. If you do not have any of these, you'll need to add around $500 to the total project cost.

**Note**: Make sure to go through the list below to make sure you have everything you need.

### The PCBs

The electronics of the rover consist of two boards: the brain board and the motor board. To order these boards we suggest that you order from [JLCPCB](https://jlcpcb.com/), this PCB fabrication company is quite inexpensive for this board size and has good turnaround time. You'll either have to order the required minimum of 10 pieces or you can ask on the Slack group whether someone wants to put in a group order or already has some extras.
Upload the [.zip files](../electrical/pcb/control_board/gerbers/v2.0.2/) individually and make sure the following settings are set:

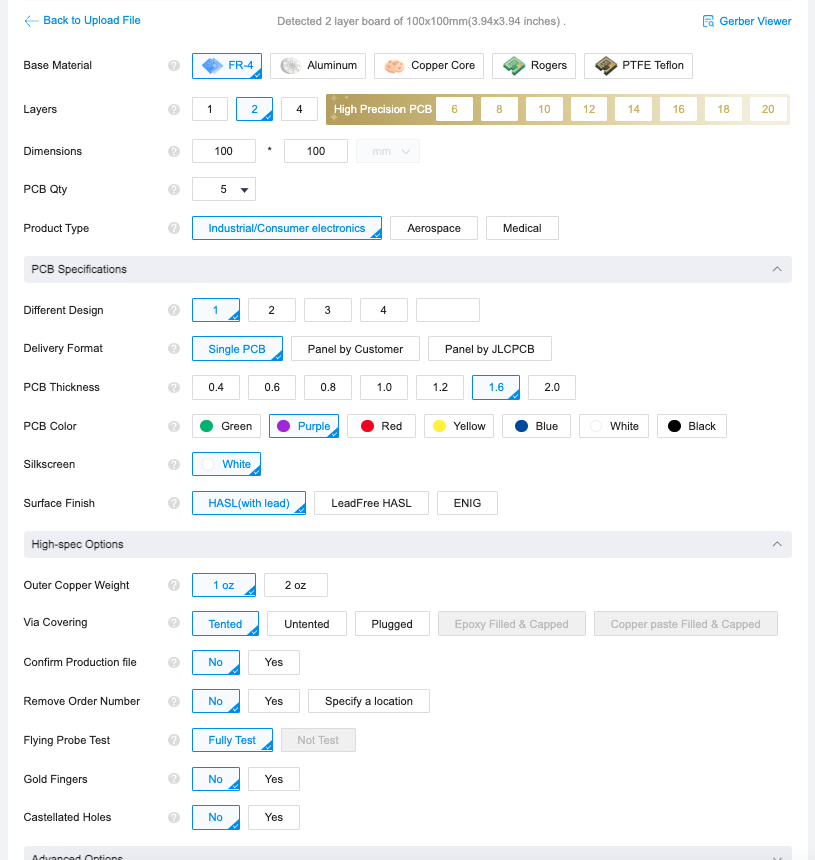
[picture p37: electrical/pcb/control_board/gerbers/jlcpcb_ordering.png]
jlcpcb settings


### The body plates

The body plates that attach to all sides of the body are designed to be made from laser cut acrylic, MDF, hardwood, or similar. The 2D cutout files are the `.dxf` files in the [laser cut parts folder](../mechanical/body/laser_cut_parts/README.md). They were designed to be around 3mm thick (1/8"). You can choose a material and cut them at your local makerspace's laser cutter or order them from an online service like [Sculpteo](https://www.sculpteo.com) or [SendCutSend](https://sendcutsend.com/). Check the README in that folder for more details.

### A gamepad or remote controller

This is technically not a requirement, especially if you're planning on making the rover autonomous, but is highly recommended. Any USB based option should work here.

Some options are getting an XBox controller with a usb dongle or for longer range; the pricier [Spektrum WS2000](https://www.spektrumrc.com/product/ws2000-wireless-simulator-usb-dongle/SPMWS2000.html) with [Spektrum DXs](https://www.spektrumrc.com/product/dxs-transmitter-only/SPMR1010.html) transmitter. Many alternatives exist and will work ok.

## Standoff kit for the boards

You'll want these to mount the PCBs to the rover body. Many options exist here, for example [this kit](https://www.amazon.com/HELIFOUNER-Spacers-Standoffs-Assortment-Tweezers/dp/B0B25BKNKK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).

## Wiring

We recommend getting spools of 18AWG (red and black), 20AWG (white, red, black) and 22AWG wire (4 colors). The wire has to be stranded and not solid core as it will bend during operation. For each wire type, if possible, get ribbon cable where each wire is attached to another one which will help with keeping wiring clean and manageable.

To protect the cables from chafing against the sharp aluminum parts, we recommend [cable sleeves](https://www.amazon.com/Best-Sellers-Cable-Sleeves/zgbs/electronics/6577542011).
You can also use [grommets](https://www.gobilda.com/plastic-grommet-14-1-12-pack/), filing down the sharp edges or burs, applying tape to the edges, or using expandable wire sleeving.

Heat shrink is a must have for keeping cables nice and snug.

Take a look at the [wiring overview](../electrical/wiring/README.md#overview) to get an idea of what you will be building. You'll need crimps and connectors for DuPont, Bullet, XT30, JST, and Molex styles. Crimping doesn't have a 100% success rate, so we recommend getting extras or buying a kit if you're planning on using them for other projects as well. Here are some options for each set you need:

* A Raspberry Pi ribbon cable, e.g. from [Adafruit](https://www.adafruit.com/product/1988) but available in many places. While you could use header pins for this connection, the cable is the cleanest solution
* A USB-C power breakout cable if you're using a Raspberry Pi 5, e.g. from [Amazon](https://www.amazon.com/dp/B0D2C74PLY)
* XT30 connectors for the power connections on the motor PCB.
  * DIY options, either:
    * [5 pairs M/F from Gobilda](https://www.gobilda.com/xt30-connector-pack-fh-mc-x-5-mh-fc-x-5/)
    * [20 pairs M/F from Amazon](https://www.amazon.com/gp/product/B0875MBLNH/ref=ppx_yo_dt_b_search_asin_title?ie=UTF8&psc=1)
    * [1 pair M/F from Digikey](https://www.digikey.com/en/products/detail/dfrobot/FIT0586/9559255)
  * premade from GoBilda: 2x [male leads](https://www.gobilda.com/xt30-lead-fh-mc-300mm-length/), 2x [female leads](https://www.gobilda.com/xt30-lead-mh-fc-300mm-length/)
* 6 4-pin JST connections:
  * 6x [premade JST to jumper wires from GoBilda](https://www.gobilda.com/encoder-breakout-cable-4-pos-jst-xh-mh-fc-to-4-x-1-pos-tjc8-mh-fc-300mm-length/)
  * [JST connector kit](https://www.amazon.com/460PCS-XH2-54-Connector-Terminal-Connectors/dp/B09DBGVX5C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)
* 6 6-pin Molex PCI-E connections. Digikey carries a couple options. In either case, be sure to get enough for 6 connectors.
  * [housings](https://www.digikey.com/en/products/detail/molex/0469920610/5116009) and [pins](https://www.digikey.com/en/products/detail/molex/0039000077/1643440)
  * [assemblies](https://www.digikey.com/en/products/detail/molex/2153261063/13883006) are sometimes available but the 16 AWG wire may be difficult to work with
* 4 3-pin DuPont and 8 4-pin DuPont connectors
  * [DuPont connector kit](https://www.amazon.com/Twidec-Connector-Terminals-Crimping-Connectors/dp/B0B152WRSW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)
  * Buy precrimped wires+connectors from various sources
* 12 female 3.5mm Bullet connectors. Make sure you're getting the right size connectors and ones that come insulated.
  * GoBilda has [various combinations](https://www.gobilda.com/connector-style-3-5mm-bullet/) available that you can cut/solder/crimp. They use 16AWG wire which is on the thicker side. Make sure you're getting the Female connector type.
  * Buy a DIY kit
    * The GoBilda [connector pack](https://www.gobilda.com/3-5mm-bullet-connector-pack-mh-fc-x-5-fh-mc-x-5/) is good quality but only has 5 female connectors so you would need 3 of them.
    * [from Amazon](https://www.amazon.com/Davitu-Electrical-Equipments-Supplies-Transparent/dp/B089W96QW1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) (insulators are flimsy but ok)

## Threadlocker

You will want threadlocker for several screws so that they don't unscrew themselves while driving. You can find this everywhere, for example at [Gobilda](https://www.gobilda.com/loctite-threadlocker-blue-242-6ml/). Make sure you get blue as opposed to red so it's not permanent.

## Tools

* A [combination nut driver](https://www.gobilda.com/7mm-combination-nut-driver/) will save you time screwing and unscrewing (lock)nuts inside the body.
* You'll need 2.5mm and 3mm hex keys for the button and socket M4 screws respectively. For example [Gobilda 2.5](https://www.gobilda.com/wera-tools-2-5mm-ball-end-hex-plus-l-key/) and [Gobilda 3](https://www.gobilda.com/wera-tools-3mm-ball-end-hex-plus-l-key/).
* A crimping tool for Molex, JST, DuPont connectors. A regular crimping tool should be able to handle all of these without issue. While you can technically complete a crimp without a crimping tool, it often won't be as consistent or strong as with a proper crimper. Various connector sets come with a decent crimper.

## Electrical

* Voltage Regulators:
  * **1 X** 5V Regulator: [Pololu](https://www.pololu.com/product/2881)
  * **1 X** 12V Regulator: [Pololu](https://www.pololu.com/product/2855)
* **3 X** Roboclaw 2x7A Motor Controller [Basic Micro](https://www.basicmicro.com/Roboclaw-2x7A-Motor-Controller_p_55.html)
* **1 X** Power Measurement Unit INA260: Sold out on DigiKey, possible replacements are on [Adafruit](https://www.adafruit.com/product/4226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)
* **1 X** PCA9685 steering servo driver [Mouser](https://www.mouser.com/ProductDetail/Adafruit/815?qs=GURawfaeGuCGKbWyy9179Q%3D%3D)
* DC power meter: [Amazon](https://www.amazon.com/gp/product/B017FSED9I/). This LCD display reads out current, voltage, power, and energy, and can be put on the back where the rectangular hole is in the laser cut cover.
* batteries: many options available here. We recommend getting LiPo batteries. You'll need a battery that can provide over 14V(*), so a 4s battery works well. You can get batteries with various mAh ratings (how many milliAmperes the battery can output for 1 hour). We recommend any option over 4000mAh. Higher capacity comes at a higher cost. You can also get more than one battery and swap them out. The rover can carry them as well.
  * Zeee sells many options [on Amazon](https://www.amazon.com/stores/page/25B7018D-26CC-4E43-BC6D-EFAF737D8F5E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)
  * You'll also need a charger for the battery. Make sure it can support the battery you bought, chemistry-wise and connector-wise. For the Zeee options, this [B6 Lipo Balance Charger](https://a.co/d/02mprFri) from Amazon will work.
  * Consider getting a fireproof battery bag. LiPo batteries are extremely flammable/explosive and a fire caused by a battery is extremely difficult to put out.
  * You'll also need a way to connect your battery to the PCB via a XT30 connector (MH-FC) which depends on the battery you get. Often these come with the charger for the battery
* A Raspberry Pi 3, 4, or 5 and SD card for the operating system. For the 4 or 5, any amount of RAM should work just fine. Note that only the 5 has two full serial interfaces and thus is the only model that can connect to the motor controllers (Roboclaws) and run bluetooth at the same time.

> (*) The reason you need 14V is that the 12V regulator needs a [dropout voltage](https://www.pololu.com/product/2855#dropout) on top of the output voltage in order to provide 12V. A 12V battery will not work adequately.

## Different wheels

* The wheels we previously included as the default from [DollarHobbyz](https://www.dollarhobbyz.com/collections/all/products/traxxas-2-talon-tires-gemini-black-chrome-wheels-5374x) are $34.95 per pair of two for a total of $104.85 (excl. shipping), saving ~$135 compared to the default Wasteland wheels. They are a perfectly fine choice but require some drilling to fit to the motor hubs.
* Gobilda also sells a larger version of the [Wasteland Wheel at 192mm diameter](https://www.gobilda.com/wasteland-wheel-192mm-diameter-72mm-width/). This adds $90 total compared to the default Wasteland wheels. No drilling is required. Those wheels are bigger and wider and look like this:

| smaller Wasteland wheels | bigger Wasteland wheels |
| --- | --- |
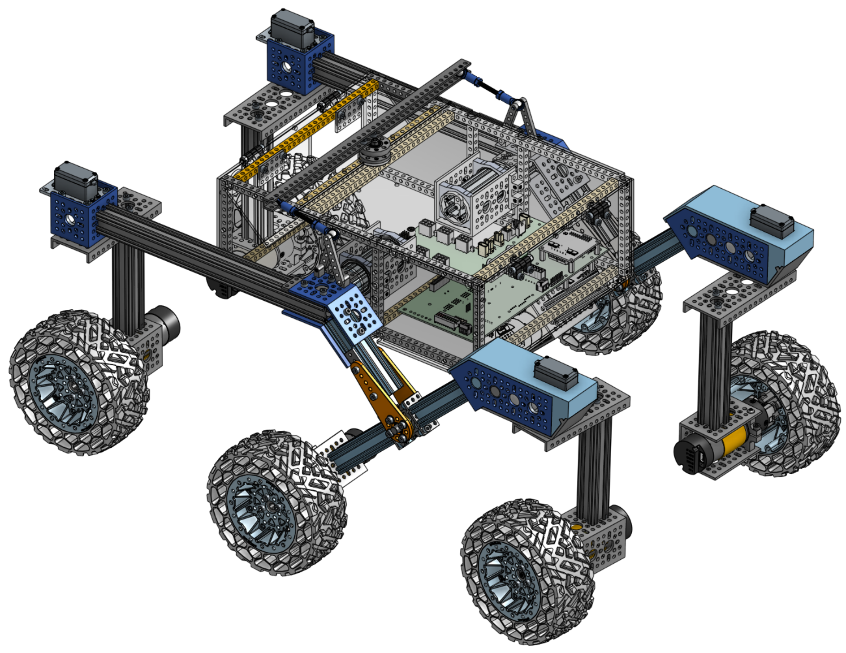
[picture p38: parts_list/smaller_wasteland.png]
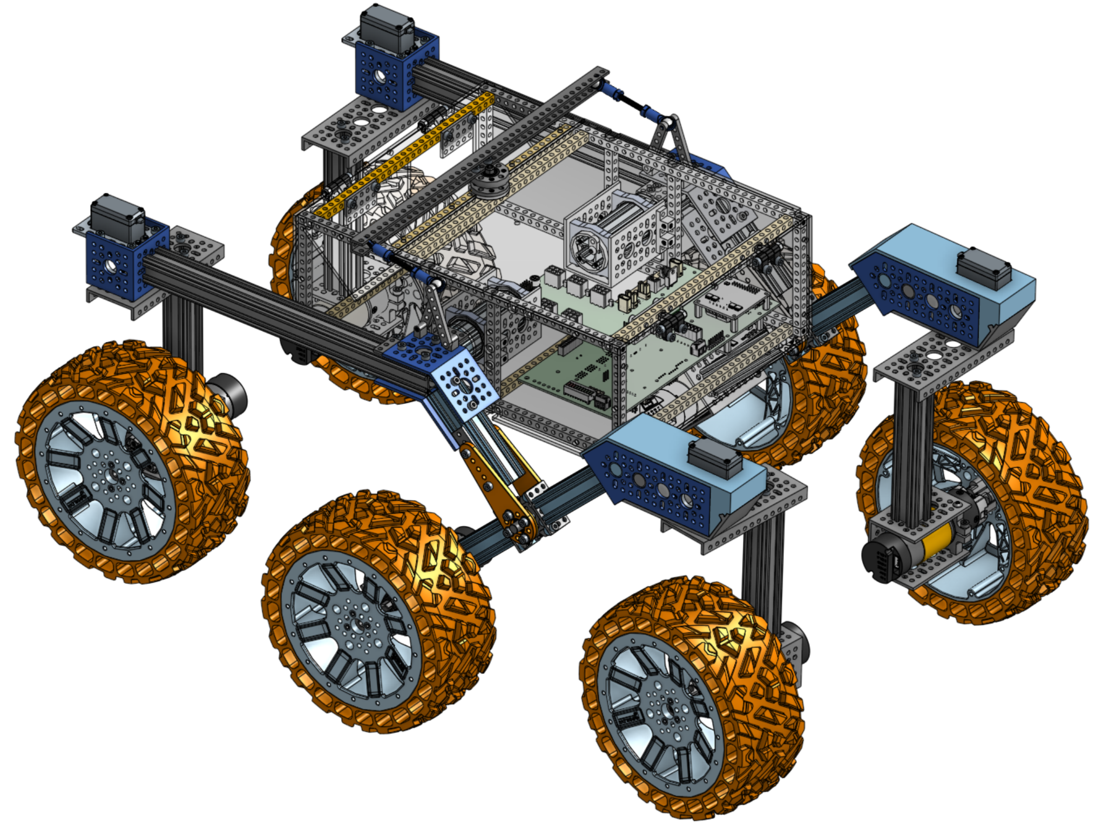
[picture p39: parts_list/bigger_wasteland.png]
|  |  |

There is a software parameter where you can easily modify the size of the wheels to account for speed differences.

# Maintaining the Parts List

Parts can become out of stock or discontinued in the future. In this case, the part list can be modified by editing `parts_list.csv`, which covers all the mechanical parts, `digikey_bom.csv`, which covers most of the electrical part, and `extra_parts.md` to cover the rest. After doing so, you can compile to update the `README.md` file using `csv_to_md.py` (The compilation will also happen automatically with a merge). **Do not** edit `README.md` directly, as it will be overwritten by the compilation process.

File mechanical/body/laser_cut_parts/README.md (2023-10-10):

# Laser cut parts

Contains the files required to cut the body plates.

> **Note**: The side plates and 'gap slats' are identical and so only one file is included. Make sure you include **two side plates and two gap slats** when you get it laser cut!

## Ordering

Various companies will allow you to order laser cut parts with them with fast turnaround times. Some options:

* [SendCutSend](https://sendcutsend.com/)
* [Sculpteo](https://www.sculpteo.com)

Formats provided:

* 2D: DXF and SVG
* Engrave: PDF

You are free to pick different materials and colors. Using SendCutSend, your cart should look something like this:

### Shareable carts

You can skip the DXF upload steps when using SendCutSend by using [this premade cart](https://cart.sendcutsend.com/eagotwf9yciz). 

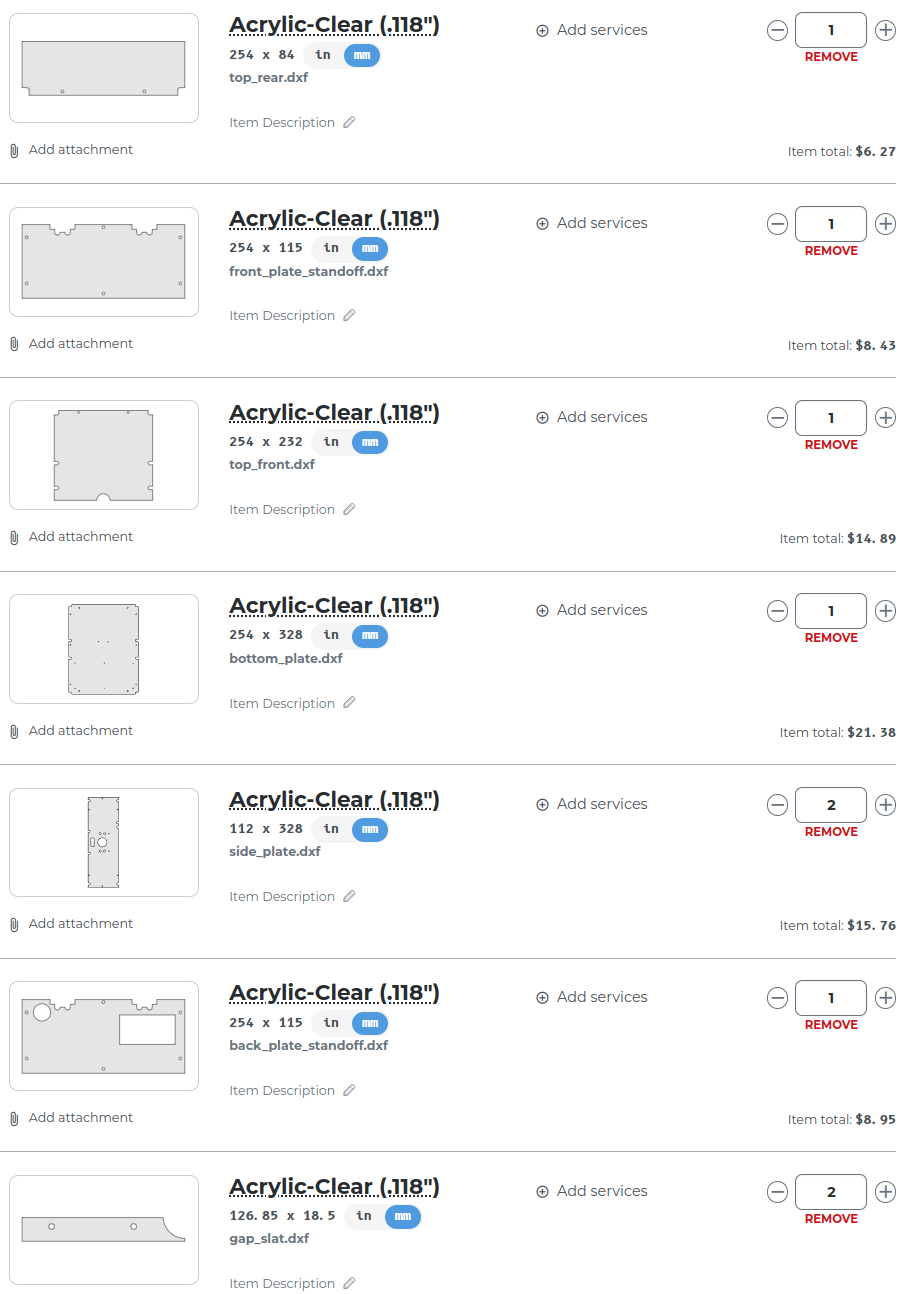
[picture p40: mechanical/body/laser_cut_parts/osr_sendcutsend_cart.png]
sencutsend cart


## Optional: Engrave the mission patch

Front plates with the Rover patch logo as an engraving have been included as PDF files. There are two versions. The 'Opaque' version requires that the logo be engraved on the top surface of the material. The 'Clear' version allows the engraving to be on the bottom side so the top surface is smooth. 

## Changelog

* Use 22mm standoffs.
* All holes have been made slightly larger to better accomodate the M3 screws. The size of the switch hole on the rear plate is also slightly larger. 
* Some of the holes on the side and bottom plates have been moved to simplify assembly.

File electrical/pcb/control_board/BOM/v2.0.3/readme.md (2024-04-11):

"bom_v2.0.3_board_ref_parts.csv" are the parts that can be directly obtained from the BOM output in kicad

"bom_v2.0.3_other_parts.csv" are ones that are part of more complex footprints, or peripheral parts

"digikey_bom_4-20-2023.csv" is the BOM to order from digikey. Must be kept in sync with the other files.

Use the "upload a file" option in digikey to upload the bom csv - see the image in this dir [digikey_upload_bom.png](./digikey_upload_bom.png)

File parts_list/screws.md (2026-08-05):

# Screws tally

All of the below are included in the [parts list](README.md). This document is for maintenance only.

## M4

| subassembly  | nb  | length | type | purpose | multiplier | total |
| --- | --- | --- | --- | --- | --- | ----- |
| wheel | 3 | **16** or 18 | socket | wheel - motor | 6 | 18 |
| wheel | 4 | 10 | either | motor - channel | 6 | 24 |
| wheel | 3 | 10 | button | bracket - vert. extrusion | 6 | 18 |
| wheel | 3 | **10** or 12 | socket | wheel - motor axis clamp | 6 | 18 |
| corner | 3 | 10 | button | vert. extrusion - low channel  | 4 | 12 |
| corner | 3 | 10 | button | low channel - servo shaft | 4 | 12 |
| corner | 3 | 10 | either | servo bracket - rocker | 4 | 12 |
| corner | 3 | 10 | either | servo bracket - rocker | 4 | 12 |
| corner | 6 | 6 or 8 or **10** | button | servo - channel | 4 | 24 |
| rocker-bogie | 8 | 12 | socket | rocker-bogie joint | 2 | 16 |
| rocker-bogie | 8 | **10** or 12 | socket | rocker-bogie joint - extrusion | 2 | 16 |
| rocker-bogie | 13  | 8 | socket | rocker-bogie - body-axis | 2 | 26 |
| rocker-bogie | 2 | 6 or **8** | socket | rocker-bogie - diff pivot | 2 | 4 |
| rocker-bogie | 8 | 8 | socket | rocker-bogie joint | 2 | 16 |
| rocker-bogie | 6 | 10 | socket | rocker-bogie joint | 2 | 12 |
| rocker-bogie | 4 | 10 or **12** | socket | diff pivot - rocker-bogie | 1 | 4 |
| rocker-bogie | 4 | **20** or 22 | socket | turnbuckles | 1 | 4 |
| rocker-bogie | 2 | 6 | button | diff pivot shaft - bearing | 1 | 2 |
| body | 28  | 16 | socket | structure | 1 | 28 |
| body | 34  | 16 | button | body plates | 1 | 34 |
| body axis | 4 | 18 or **20** | socket | axis - body | 2 | 8 |
| body axis | 8 | **6** or 8 | button | bearing - channel | 2 | 16 |
| body axis | 2 | 6 | either | axis cap | 2 | 4 |
| hinges | 2 | **6** or 8 | button | | 4 | 8 |
| hinges | 2 | 6 or **8** | either | | 4 | 8 |
| hinges | 2 | 14 or **16** | either | | 4 | 8 |
| hinges | 1 | 10 | button | | 4 | 4 |

When multiple options are available, the bold value is selected.

Total per category and length:

| type | length | min required | Gobilda # of 25-packs |
| --- | --- | --- | --- |
| button | [6](https://www.gobilda.com/2802-series-zinc-plated-steel-button-head-screw-m4-x-0-7mm-6mm-length-25-pack/) | 10 (+4) | 2 |
| button | [10](https://www.gobilda.com/2802-series-zinc-plated-steel-button-head-screw-m4-x-0-7mm-10mm-length-25-pack/) | 70 (+48) | 3 |
| button | [16](https://www.gobilda.com/2802-series-zinc-plated-steel-button-head-screw-m4-x-0-7mm-16mm-length-25-pack/) | 34 | 2 |
| socket | [8](https://www.gobilda.com/2800-series-zinc-plated-steel-socket-head-screw-m4-x-0-7mm-8mm-length-25-pack/) | 30 (+8) | 2 |
| socket | [10](https://www.gobilda.com/2800-series-zinc-plated-steel-socket-head-screw-m4-x-0-7mm-10mm-length-25-pack/) | 46 (+52) | 4 |
| socket | [12](https://www.gobilda.com/2800-series-zinc-plated-steel-socket-head-screw-m4-x-0-7mm-12mm-length-25-pack/) | 20 | 1 |
| socket | [16](https://www.gobilda.com/2800-series-zinc-plated-steel-socket-head-screw-m4-x-0-7mm-16mm-length-25-pack/) | 46 (+8) | 2 |
| socket | [20](https://www.gobilda.com/2800-series-zinc-plated-steel-socket-head-screw-m4-x-0-7mm-20mm-length-25-pack/) | 12 | 1 |

Values between parentheses are the additional screws that would need to be ordered if all 'either' types with same length are used in that type. In general, socket screws are preferred because of their resistance to stripping and use of a larger hex key.

The parts list also includes 1 [25-pack of M4 washers](https://www.gobilda.com/2801-series-zinc-plated-steel-washer-4mm-id-x-8mm-od-25-pack/), 2 [25-pack of M4 hex nuts](https://www.gobilda.com/2811-series-zinc-plated-steel-hex-nut-m4-x-0-7mm-7mm-hex-25-pack/), and 1 [25-pack of M4 locking hex nuts](https://www.gobilda.com/2812-series-zinc-plated-steel-nylon-insert-locknut-m4-x-0-7mm-7mm-hex-25-pack/).

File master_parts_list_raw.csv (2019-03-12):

Part Name | Project Ref Code | Model/Config | Site | Link | Sold in Packs of | Total Used in Project | Quantity to Buy | Price Each | Price Total | Used in Sections
#6-32 x 1/4 Button Head Screw | B1 | 92949A144 | McMaster | https://www.mcmaster.com/92949a144 | 100 | 212 | 3 | $3.45 | $10.35 | Body, Corner Steering, Differential Pivot, Mechanical Integration, Wheel Assembly
M2.5 x 6mm Screw | B10 | 92095a458 | McMaster | https://www.mcmaster.com/92095a458 | 25 | 12 | 1 | $7.07 | $7.07 | Body
#6-32 Locknuts | B11 | 90631A007 | McMaster | https://www.mcmaster.com/90631A007 | 100 | 88 | 1 | $2.72 | $2.72 | Body, Differential Pivot, Rocker-Bogie
#4-40 Locknuts | B12 | 90631A005 | McMaster | https://www.mcmaster.com/90631A005 | 100 | 8 | 1 | $2.79 | $2.79 | Differential Pivot, Head Assembly
#2-56 x 3/16” Button Head Screws | B13 | 91255A076 | McMaster | https://www.mcmaster.com/91255A076 | 25 | 4 | 1 | $3.76 | $3.76 | Body
#6-32 x 3/8 Button Head Screw | B2 | 92949A146 | McMaster | https://www.mcmaster.com/92949A146 | 100 | 80 | 1 | $3.72 | $3.72 | Body, Head Assembly, Rocker-Bogie
#6-32 x 1/2 Button Head Screw | B3 | 92196A148 | McMaster | https://www.mcmaster.com/92949A148 | 100 | 12 | 1 | $3.72 | $3.72 | Body, Wheel Assembly
#6-32 x 5/8 Button Head Screw | B4 | 92196A150 | McMaster | https://www.mcmaster.com/92949A150 | 100 | 32 | 1 | $4.07 | $4.07 | Rocker-Bogie
#6-32 x 3/4 Button Head Screw | B5 | 92196A151 | McMaster | https://www.mcmaster.com/92949A151 | 100 | 16 | 1 | $4.41 | $4.41 | Corner Steering
#6-32 x 1.0 Button Head Screw | B6 | 96006A252 | McMaster | https://www.mcmaster.com/92949A153 | 50 | 4 | 1 | $5.42 | $5.42 | Body
#6-32 x 1.25 Button Head Screw | B7 | 92949A160 | McMaster | https://www.mcmaster.com/92949A160 | 50 | 20 | 1 | $6.51 | $6.51 | Differential Pivot, Wheel Assembly
#4-40 x 1/4 Button Head Screw | B8 | 92949A106 | McMaster | https://www.mcmaster.com/92949a106 | 100 | 84 | 1 | $2.87 | $2.87 | Body, Head Assembly
#4-40 x 1.25 Button Head Screw | B9 | 92949A118 | McMaster | https://www.mcmaster.com/92949A118 | 100 | 4 | 1 | $7.70 | $7.70 | Differential Pivot
Raspberry pi 3 model b | E1 | B | Amazon | https://www.amazon.com/Raspberry-Model-1-2GHz-64-bit-quad-core/dp/B01CD5VC92?s=electronics | 1 | 1 | 1 | $34.99 | $34.99 | Body, Electrical Build
3 pin Micro Connectors | E10 | CA-MIC3-W3-NC-1 | US Digital | https://www.usdigital.com/products/cables-connectors/cables/3-pin/CA-MIC3-W3-NC | 1 | 4 | 4 | $6.80 | $27.20 | Electrical Build
Logic Shifter | E11 | 74LVC245 | Adafruit | https://www.adafruit.com/product/735 | 1 | 2 | 2 | $1.50 | $3.00 | Head Assembly, PCB Testing
Battery | E12 | Standard Tamiya Connectors | BatterySpace | https://www.batteryspace.com/li-ion-battery-14-8v-5-2ah-77wh-8a-rate-for-diving-light---un-38-3-passed.aspx | 1 | 1 | 1 | $86.95 | $86.95 | Electrical Build
Battery Charger | E13 | Standard Tamiya Connectors | BatterySpace | https://www.batteryspace.com/smart-charger-3-0a-for-14-8v-li-ion-polymer-battery-pack.aspx | 1 | 1 | 1 | $41.95 | $41.95
Wire Braid | E14 | 100 Ft | Amazon | https://www.amazon.com/PET-Expandable-Braided-Sleeving-10ft/dp/B00ZATM676?th=1 | 1 | 1 | 1 | $25.00 | $25.00
Battery Volt Meter | E15 |  | Amazon | https://www.amazon.com/DROK-Multimeter-6-5-100V-Backlight-Measuring/dp/B017FSED9I | 1 | 1 | 1 | $13.24 | $13.24 | Electrical Build
SD Card | E16 | 8Gb | Amazon | https://www.amazon.com/SanDisk-Ultra-Micro-Adapter-SDSQUNC-016G-GN6MA/dp/B010Q57SEE | 1 | 1 | 1 | $9.98 | $9.98
Jumper Wire Pack | E17 | 6inch | Adafruit | https://www.adafruit.com/product/826 | 1 | 5 | 5 | $3.95 | $19.75
4” and 8" Female/Female Jumper Wires | E18 |  | Amazon | https://www.amazon.com/GenBasic-Female-Solderless-Breadboard-Prototyping/dp/B01L5ULRUA | 40 | 200 | 5 | $5.99 | $29.95 | Electrical Build
Raspberry pi heatsink | E19 |  | Amazon | https://www.amazon.com/Mudder-Aluminum-Heatsink-Cooling-Raspberry/dp/B01GE7Q060 | 1 | 1 | 1 | $6.79 | $6.79
Roboclaw Motor Driver | E2 |  | Pololu | https://www.pololu.com/product/3284 | 1 | 5 | 5 | $69.95 | $349.75 | Body, Electrical Build
Resistors 10K | E22 | CF14JT10K0CT-ND | Digikey | https://www.digikey.com/product-detail/en/stackpole-electronics-inc/CF14JT10K0/CF14JT10K0CT-ND/1830374 | 1 | 4 | 4 | $0.04 | $0.16 | PCB Testing
Resistors 22K | E23 | CF14JT22K0CT-ND | Digikey | https://www.digikey.com/product-detail/en/stackpole-electronics-inc/CF14JT22K0/CF14JT22K0CT-ND/1830383 | 1 | 4 | 4 | $0.04 | $0.16 | PCB Testing
Tamiya Connectors | E24 | E19 | Amazon | https://www.amazon.com/Tamiya-Male-Female-150mm-Venom/dp/B000HKEVH6 | 1 | 1 | 1 | $5.57 | $5.57 | Electrical Build
Switch | E25 | 432-1282-ND | Digikey | https://www.digikey.com/product-detail/en/bulgin/C3900BA/1091-1026-ND/2747857 | 1 | 1 | 1 | $4.49 | $4.49 | Electrical Build
4.7k Ohm Resistor | E26 | CF14JT4K70CT-ND | Digikey | https://www.digikey.com/products/en?keywords=CF14JT4K70CT-ND | 1 | 1 | 1 | $0.04 | $0.04 | PCB Testing
Heat Shrink Tubing | E27 | 532 pc | Amazon | https://www.amazon.com/Shrink-Tubing-Black-532pcs-innhom/dp/B075WR9FVL | 1 | 1 | 1 | $7.99 | $7.99
Black Wire 16AWG | E28 | C76512B-50-ND | Digikey | https://www.digikey.com/products/en?keywords=C76512B-50-ND | 1 | 1 | 1 | $15.59 | $15.59 | Electrical Build
Red Wire 16AWG | E29 | C76512R-50-ND | Digikey | https://www.digikey.com/products/en?keywords=C76512R-50-ND | 1 | 1 | 1 | $15.59 | $15.59 | Electrical Build
0.1” Pitch Pin Header (40 pins) | E3 | S1011EC-40-ND | Digikey | https://www.digikey.com/products/en?keywords=S1011EC-40-ND | 1 | 5 | 5 | $0.59 | $2.95 | PCB Testing
Black Wire 20AWG | E30 | CN538B-50-ND | Digikey | https://www.digikey.com/products/en?keywords=CN538B-50-ND | 1 | 2 | 2 | $12.56 | $25.12 | Electrical Build
Red Wire 20AWG | E31 | CN541R-50-ND | Digikey | https://www.digikey.com/products/en?keywords=CN541R-50-ND | 1 | 2 | 2 | $15.59 | $31.18 | Electrical Build
Black Wire 30AWG | E32 | C2003B-50-ND | Digikey | https://www.digikey.com/products/en?keywords=C2003B-50-ND | 1 | 1 | 1 | $6.32 | $6.32
Red Wire 30AWG | E33 | C2015R-50-ND | Digikey | https://www.digikey.com/products/en?keywords=C2015R-50-ND | 1 | 1 | 1 | $6.14 | $6.14
White Wire 30AWG | E34 | 1528-1737-ND | Digikey | https://www.digikey.com/products/en?keywords=1528-1737-ND | 1 | 1 | 1 | $4.95 | $4.95 | Electrical Build
Blue Wire 30AWG | E35 | 1528-1734-ND | Digikey | https://www.digikey.com/products/en?keywords=1528-1734-ND | 1 | 1 | 1 | $4.95 | $4.95 | Electrical Build
Yellow Wire 30AWG | E36 | 1528-1735-ND | Digikey | https://www.digikey.com/products/en?keywords=1528-1735-ND | 1 | 1 | 1 | $4.95 | $4.95 | Electrical Build
Green Wire 30AWG | E37 | 1528-1736-ND | Digikey | https://www.digikey.com/products/en?keywords=1528-1736-ND | 1 | 1 | 1 | $4.95 | $4.95 | Electrical Build
5V Buck Boost Regulator | E4 |  | Pololu | https://www.pololu.com/product/2851 | 1 | 2 | 2 | $14.95 | $29.90 | Body, Electrical Build
Gear Motor w Relative Enc. (Drive Motor) | E5 | 172:1 gear ratio, with relative encoder | Pololu | https://www.pololu.com/product/3268 | 1 | 6 | 6 | $34.95 | $209.70 | Wheel Assembly
Gear Motor (Corner Motor) | E6 | 172:1 gear ratio, NO relative encoder | Pololu | https://www.pololu.com/product/3232 | 1 | 4 | 4 | $19.95 | $79.80 | Corner Steering
Absolute Encoder | E7 | 1/8 inch, 10 Bit Analog, Sleeve Bushing (N) | US Digital | https://www.usdigital.com/products/encoders/absolute/rotary/shaft/MA3 | 1 | 4 | 4 | $55.50 | $222.00 | Corner Steering
LED Array | E8 |  | Adafruit | https://www.adafruit.com/product/420 | 1 | 1 | 1 | $24.95 | $24.95 | Head Assembly
Op Amp LM 358P | E9 | 296-1395-5-ND | Digikey | https://www.digikey.com/products/en?keywords=296-1395-5-ND | 1 | 4 | 4 | $0.37 | $1.48 | PCB Testing
1.5” U Channel | S1 | 585440 | ServoCity | https://www.servocity.com/1-50-channel | 1 | 6 | 6 | $2.99 | $17.94 | Body, Mechanical Integration
0.25" Pillow Bearing Block | S10 | 535110 | ServoCity | https://www.servocity.com/0-250-1-4-bore-flat-bearing-mount | 1 | 8 | 8 | $5.99 | $47.92 | Corner Steering
0.5” Pillow Block | S11 | 535118 | ServoCity | https://www.servocity.com/0-500-1-2-bore-flat-bearing-mount | 1 | 6 | 6 | $6.99 | $41.94 | Body, Rocker-Bogie
0.25” Face Tapped Clamping Hub | S12 | 545588 | ServoCity | https://www.servocity.com/770-clamping-hubs#348=95 | 1 | 4 | 4 | $5.99 | $23.96 | Wheel Assembly
0.5” Face Tapped Clamping Hub | S13 | 545600 | ServoCity | https://www.servocity.com/770-clamping-hubs#348=107 | 1 | 3 | 3 | $5.99 | $17.97 | Differential Pivot, Rocker-Bogie
4mm Face Tapped Clamp Hub | S14 | 545608 | ServoCity | https://www.servocity.com/770-clamping-hubs#348=96 | 1 | 6 | 6 | $5.99 | $35.94 | Wheel Assembly
Stainless Steel D-Shaft | S15 | 634066 | ServoCity | https://www.servocity.com/0-250-1-4-stainless-steel-d-shafting#371=276 | 1 | 4 | 4 | $1.49 | $5.96 | Corner Steering
0.5 x 3Ft Aluminum Rod | S16 | 89965K364 | McMaster | https://www.mcmaster.com/89965K364 | 1 | 1 | 1 | $23.16 | $23.16 | Differential Pivot
Dual Side mount A | S17 | 585470 | ServoCity | https://www.servocity.com/90-dual-side-mount | 2 | 8 | 4 | $5.99 | $23.96 | Body
0.5” x 4” aluminum tube | S18 | 635254 | ServoCity | https://www.servocity.com/0-500-1-2-aluminum-tubing#371=455 | 1 | 4 | 4 | $2.09 | $8.36 | Differential Pivot
0.5” x 2” aluminum tube | S19 | 635252 | ServoCity | https://www.servocity.com/0-500-1-2-aluminum-tubing#371=246 | 1 | 1 | 1 | $1.49 | $1.49 | Mechanical Integration
3” Channel | S2 | 585442 | ServoCity | https://www.servocity.com/3-0-channel | 1 | 18 | 18 | $3.99 | $71.82 | Corner Steering, Rocker-Bogie, Wheel Assembly
.5”D Bore Bottom Tapped Clamping Mount | S20 | 585546 | ServoCity | https://www.servocity.com/1-2-bore-bottom-tapped-clamping-mount | 1 | 2 | 2 | $5.99 | $11.98 | Differential Pivot
5 Hole Aluminum Beam | S21 | 585404 | ServoCity | https://www.servocity.com/1-54-aluminum-beam | 2 | 8 | 4 | $2.39 | $9.56 | Differential Pivot
0.5” D Collar Clamp | S22 | 6157K14 | ServoCity | https://www.servocity.com/aluminum-clamp-collars#368=229 | 1 | 11 | 11 | $2.26 | $24.86 | Mechanical Integration, Rocker-Bogie
4mm to .25 Clamping Shaft Coupler | S23 | 625049 | ServoCity | https://www.servocity.com/clamping-shaft-couplers-6776#348=123 | 1 | 4 | 4 | $4.99 | $19.96 | Corner Steering
Bore Clamping Hub for 1" PVC | S24 | 545512 | ServoCity | https://www.servocity.com/1-315-pvc-clamp-hub-b | 1 | 2 | 2 | $9.99 | $19.98 | Body, Head Assembly
25mm Bore Side Tapped Clamping Mount | S25 | 545680 | ServoCity | https://www.servocity.com/25mm-bore-tube-clamp | 1 | 6 | 6 | $5.99 | $35.94 | Wheel Assembly
Plain Bore Gear | S26 | RHA32-36-48 | ServoCity | https://www.servocity.com/32-pitch-acetyl-hub-gears-0-1875-face#199=15 | 1 | 4 | 4 | $3.69 | $14.76 | Wheel Assembly
Shaft Mount Pinion Gear | S27 | 615362 | ServoCity | https://www.servocity.com/0-125-1-8-bore-32p-shaft-mount-pinion-gear | 1 | 4 | 4 | $7.99 | $31.96 | Corner Steering
Custom Acrylic Electronics Board | S28 |  | Sculpteo | https://www.sculpteo.com/ | 1 | 1 | 1 | $15.25 | $15.25
5 Foot PVC | S29 | 48925K93 | McMaster | https://www.mcmaster.com/48925k93 | 1 | 1 | 1 | $4.92 | $4.92 | Head Assembly
3.75” Channel | S3 | 585443 | ServoCity | https://www.servocity.com/3-75-channel | 1 | 4 | 4 | $4.49 | $17.96 | Rocker-Bogie
Wheel | S30 |  | DollarHobbyz | https://www.dollarhobbyz.com/collections/all/products/traxxas-2-talon-tires-gemini-black-chrome-wheels-5374x | 2 | 6 | 3 | $25.27 | $75.81 | Wheel Assembly
3D Printed Encoder Mounts | S31 |  | Makexyz | https://www.makexyz.com/ | 1 | 4 | 4 | $12.90 | $51.60 | Corner Steering
RC Turnbuckles | S32 | 06048B | Amazon | https://www.amazon.com/Hobbypark-Aluminum-Turnbuckle-BRONTOSAURUS-Replacement/dp/B01H5PZKMK | 2 | 2 | 1 | $9.25 | $9.25 | Differential Pivot
3D Printed Head | S33 |  | Makexyz | https://www.makexyz.com/ | 1 | 1 | 1 | $75.80 | $75.80
Loctite Red | S34 |  | Amazon | https://www.amazon.com/Loctite-Threadlocker-Red-0-20-209741/dp/B000FP8EUS | 1 | 1 | 1 | $6.49 | $6.49 | Wheel Assembly
9” x 12” Aluminum Plate | S35 | 585006 | ServoCity | https://www.servocity.com/9-x-12-aluminum-pattern-plate | 1 | 2 | 2 | $16.99 | $33.98 | Body
Loctite 2 Part Apoxy | S36 |  | Amazon | https://www.amazon.com/Loctite-Marine-0-85-Fluid-Syringe-1405604/dp/B00KH62K50 | 1 | 1 | 1 | $5.42 | $5.42 | Wheel Assembly
4.5” x 12” Aluminum Plate | S37 | 585004 | ServoCity | https://www.servocity.com/4-5-x-12-pattern-plate | 1 | 3 | 3 | $13.99 | $41.97 | Body
Custom Acrylic Back plate | S37B |  | Sculpteo | https://www.sculpteo.com/ | 1 | 1 | 1 | $11.75 | $11.75
4.5” Channel | S4 | 585444 | ServoCity | https://www.servocity.com/4-50-channel | 1 | 4 | 4 | $4.99 | $19.96 | Wheel Assembly
9” Channel | S5 | 585450 | ServoCity | https://www.servocity.com/9-0-channel | 1 | 2 | 2 | $7.99 | $15.98 | Rocker-Bogie
Channel Connectors | S6 | 545532 | ServoCity | https://www.servocity.com/channel-connector-plate-a | 2 | 30 | 15 | $3.99 | $59.85 | Mechanical Integration, Wheel Assembly
Pattern F Bracket | S7 | 585592 | ServoCity | https://www.servocity.com/flat-bracket-f | 1 | 8 | 8 | $2.79 | $22.32 | Rocker-Bogie
Single Pattern Bracket | S8 | 585468 | ServoCity | https://www.servocity.com/flat-single-channel-bracket | 1 | 1 | 1 | $1.29 | $1.29 | Differential Pivot
Motor Mount F | S9 | 555104 | ServoCity | https://www.servocity.com/aluminum-motor-mount-f | 1 | 4 | 4 | $3.99 | $15.96 | Corner Steering
#6 x 1/4 Spacer | T1 | 92510A442 | McMaster | https://www.mcmaster.com/92510A442 | 1 | 60 | 60 | $0.23 | $13.80 | Body, Corner Steering, Rocker-Bogie
#6-32 x 0.75” Standoff | T3 | 633126 | ServoCity | https://www.servocity.com/6-32-thread-1-4-od-round-aluminum-standoffs#371=256 | 4 | 20 | 5 | $1.79 | $8.95 | Corner Steering, Wheel Assembly
#4-40 x 1/4 Threaded Standoff | T4 | 91780A162 | McMaster | https://www.mcmaster.com/91780A162 | 1 | 8 | 8 | $0.23 | $1.84 | Body
#4-40 x 1/2 Threaded Standoff | T5 | 91780A164 | McMaster | https://www.mcmaster.com/91780A164 | 1 | 12 | 12 | $0.27 | $3.24 | Body
#4-40 x 3/4 Threaded Standoff | T6 | 91780A166 | McMaster | https://www.mcmaster.com/91780A164 | 1 | 8 | 8 | $0.37 | $2.96 | Body
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

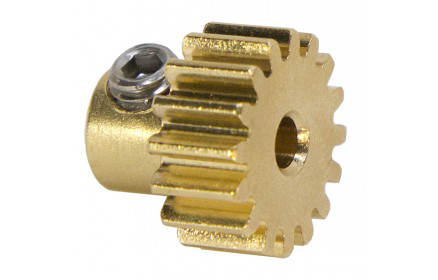
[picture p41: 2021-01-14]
images/components/structural/S27.png

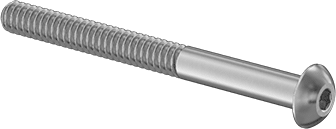
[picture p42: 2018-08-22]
images/components/screws/B9.png

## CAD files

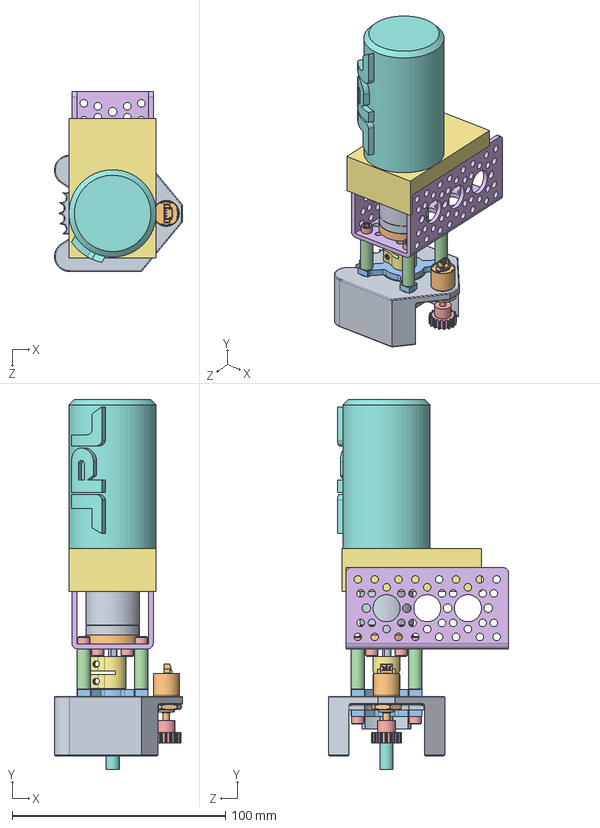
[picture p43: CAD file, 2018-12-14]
Mechanical/Corner Steering/CAD/Corner Steering Assembly.SLDASM
60.0 x 173.4 x 84.4 mm
25mm Motor
555104 screw (M3)_92005A112 x 2
6_32 standoff x 4
6-32_SHCS x 12
6-32_L0_25 Spacer x 4
4mm - 0.25in Clamping Shaft Coupler
.25 D Shaft
Encoder mount
Absolute Encoder
0.25 Beaing Block x 2
0.25 Bearing x 2
0.125in Bore 32 Pitch Shaft Mount Pinion Gear
3 Aluminum Channel
cap_base
cap_with_jpl

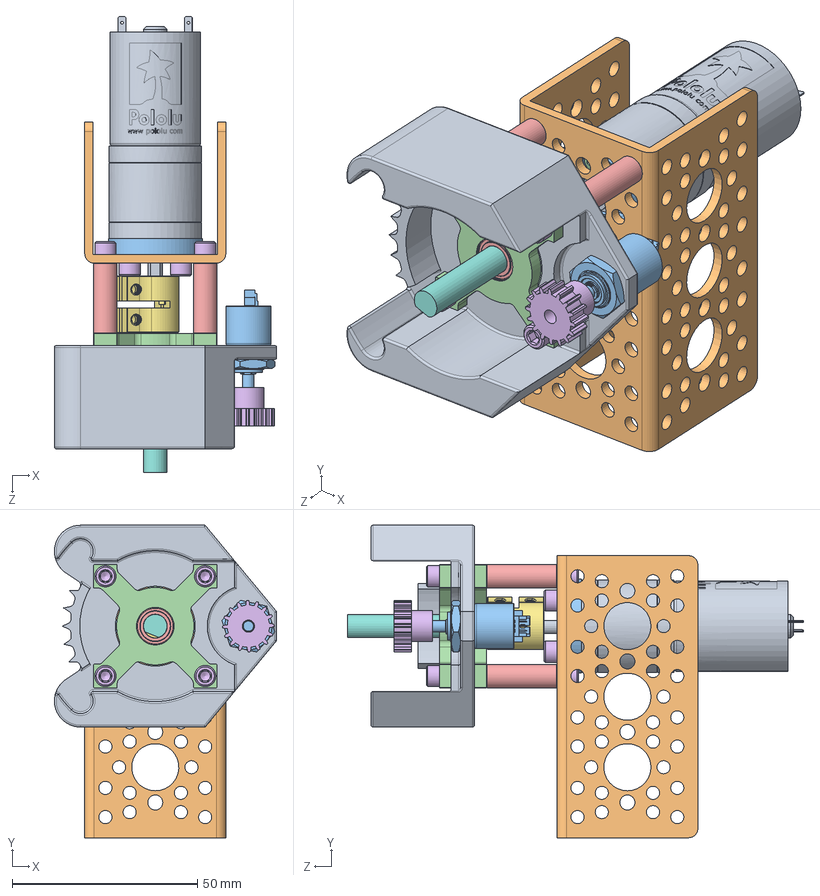
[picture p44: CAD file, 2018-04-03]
Mechanical/Mechanical Integration/CAD/Subassemblies/Corner Steering/Corner Steering Assembly.SLDASM
60.0 x 84.4 x 123.1 mm
25mm Motor
3 Aluminum Channel
555104 screw (M3)_92005A112 x 2
6_32 standoff x 4
6-32_SHCS x 12
4mm - 0.25in Clamping Shaft Coupler
.25 D Shaft
Encoder mount
6-32_L0_25 Spacer x 4
Absolute Encoder
0.25 Beaing Block x 2
0.25 Bearing x 2
0.125in Bore 32 Pitch Shaft Mount Pinion Gear

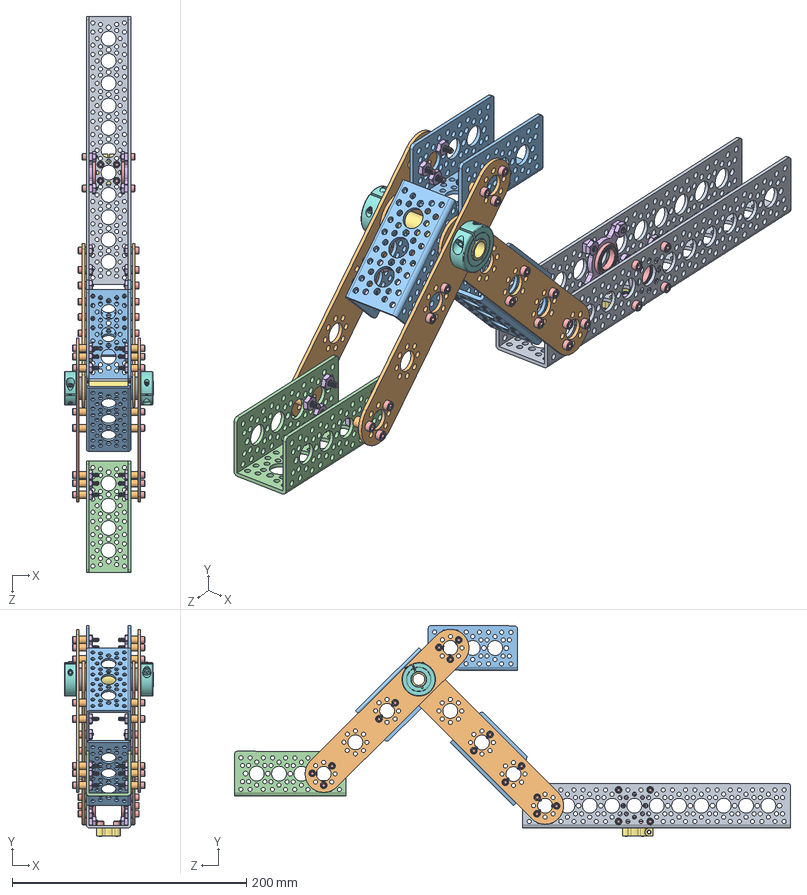
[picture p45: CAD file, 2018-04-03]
Mechanical/Mechanical Integration/CAD/Subassemblies/Rocker-Bogie/Rocker-Bogie Assembly.SLDASM
76.2 x 180.0 x 474.7 mm
9 Aluminum Channel
Pattern F Bracket x 4
3 Aluminum Channel Mod x 2
6-32 Washer x 14
6-32_SHCS x 42
hex_nut x 38
3inch Aluminum Rod
.5in Collared Clamp x 2
0.5 Nylon Plastic Washer x 6
6-32_L0_25 Spacer x 16
3 Aluminum Channel
3.75 Aluminum Channel
0.5 Bearing x 2
0.5 Bearing Block x 2

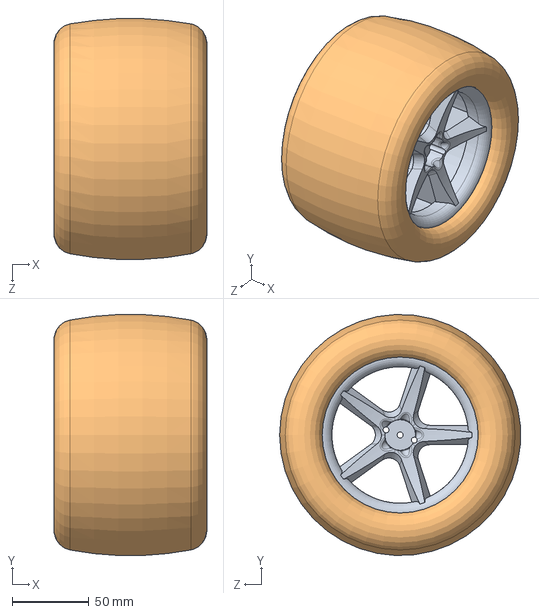
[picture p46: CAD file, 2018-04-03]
Mechanical/Wheel Assembly/CAD/Mechanical Parts/Wheel.SLDASM
99.7 x 157.1 x 156.9 mm
Wheel Rim
Wheel Tire

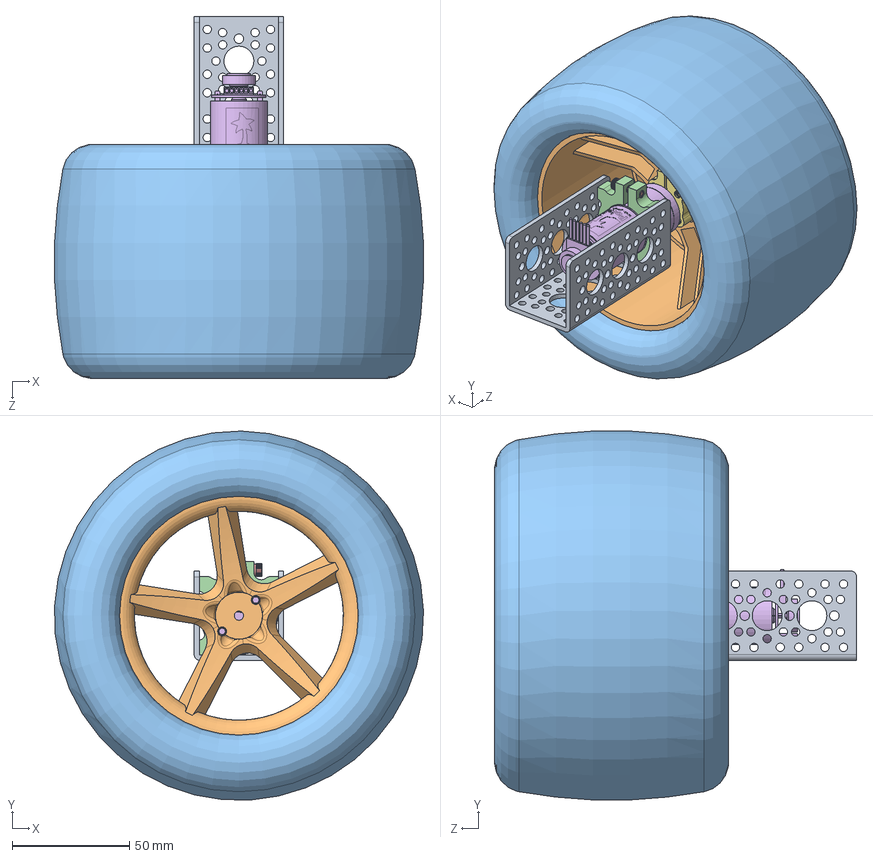
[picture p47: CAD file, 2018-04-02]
Mechanical/Wheel Assembly/CAD/Wheel Assembly.SLDASM
157.0 x 157.0 x 154.2 mm
3 Aluminum Channel
Wheel Rim
Wheel Tire
25m Bore Side Tapped Clamping Mount
#6-32 0_5 Bolt
25mm Motor and Encoder
4mm Face Tapped Clamping Hub

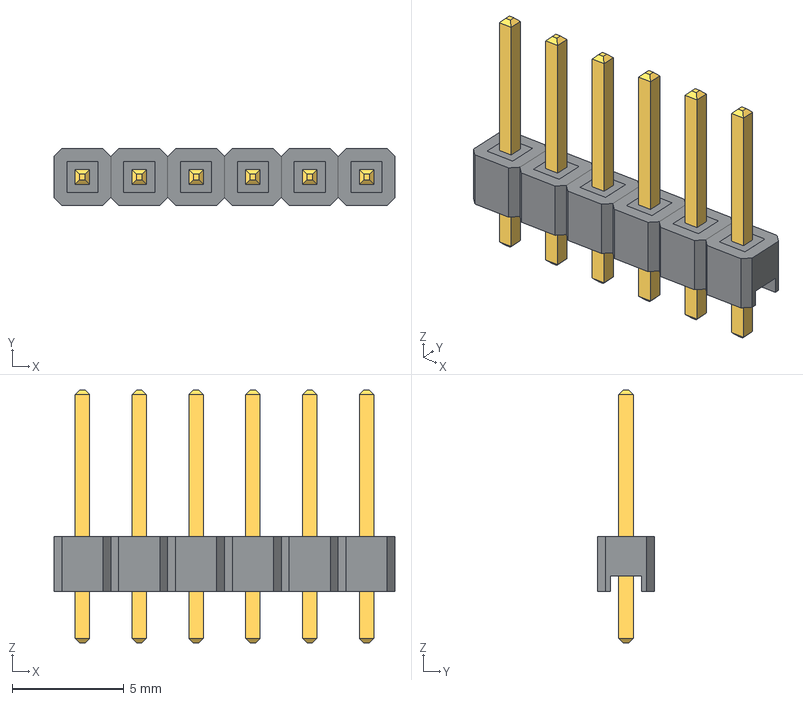
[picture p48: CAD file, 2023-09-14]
electrical/pcb/control_board/3d_models/Male Header 1x6.step
15.2 x 2.54 x 11.3 mm

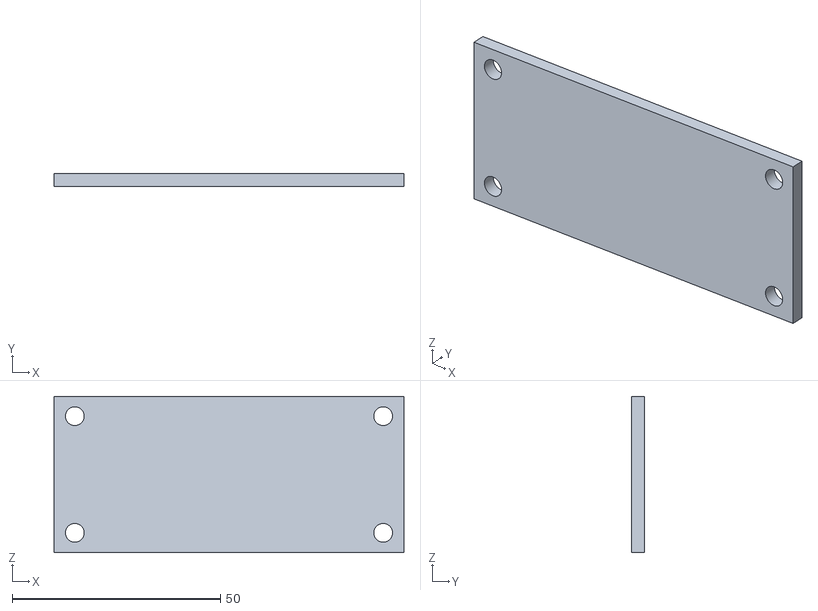
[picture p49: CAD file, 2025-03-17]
expansion/mast/3d_models/mast_backplate.stl
84.0 x 3.00 x 37.5

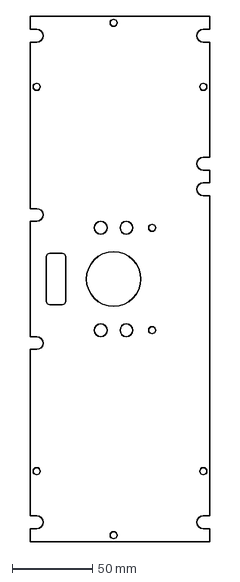
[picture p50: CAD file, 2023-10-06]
mechanical/body/laser_cut_parts/dxf/side_plate.dxf
112.0 x 328.0 mm

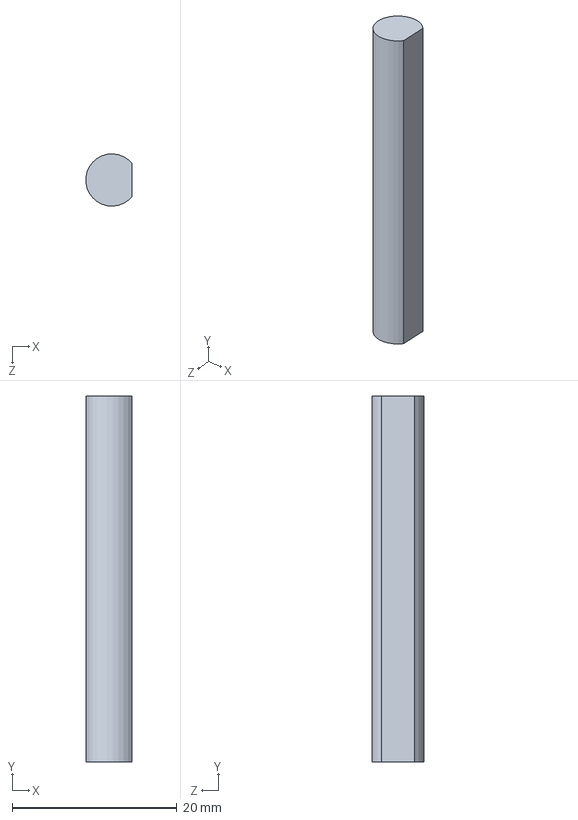
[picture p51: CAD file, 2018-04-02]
Mechanical/Corner Steering/CAD/Mechanical Parts/.25 D Shaft.SLDPRT
5.63 x 44.5 x 6.35 mm

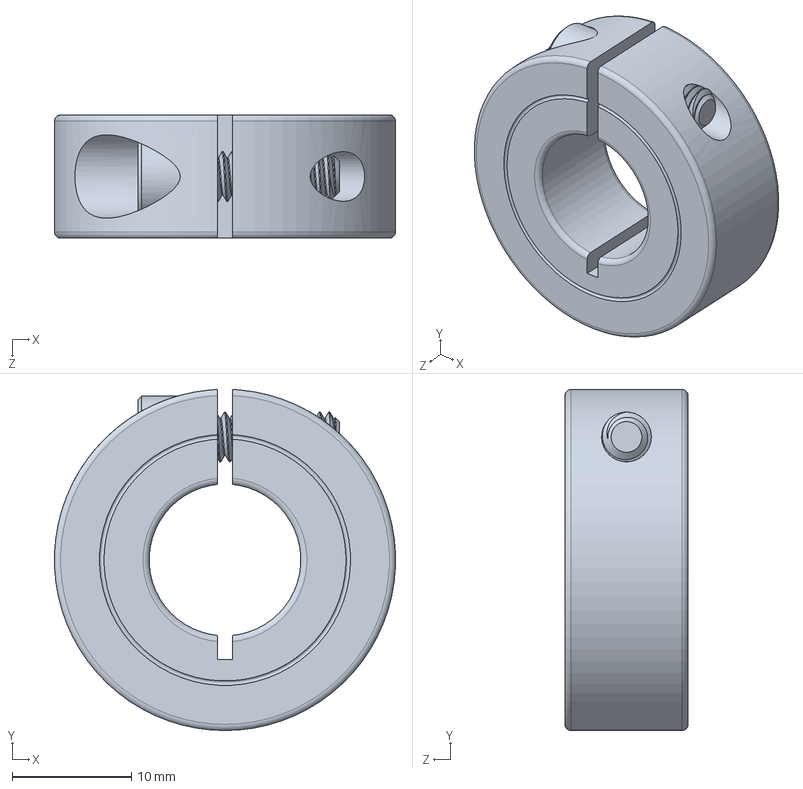
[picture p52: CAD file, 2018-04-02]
Mechanical/Final Integration/CAD/Mechanical Parts/.5in Collared Clamp.SLDPRT
28.6 x 28.6 x 10.3 mm

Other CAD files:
Mechanical/Mechanical Integration/CAD/3D Printed Parts/Low Poly Head Assembly.SLDASM .STL
Mechanical/Mechanical Integration/CAD/Subassemblies/Body/Mechanical Parts/.5in Collared Clamp.SLDPRT
Mechanical/Mechanical Integration/CAD/Subassemblies/Corner Steering/Mechanical Parts/.25 D Shaft.SLDPRT
Mechanical/Wheel Assembly/CAD/Mechanical Parts/Wheel Tire.SLDPRT
electrical/pcb/control_board/3d_models/12_channel_servo_controller_headers.step
electrical/pcb/control_board/3d_models/1726750613.stp
electrical/pcb/control_board/3d_models/277-14404-ND.step
electrical/pcb/control_board/3d_models/4527--3DModel-STEP-56544.STEP
electrical/pcb/control_board/3d_models/61204021621_Download_STP_61204021621_rev1.stp
electrical/pcb/control_board/3d_models/70246-2001_stp/702462001.stp
electrical/pcb/control_board/3d_models/B6B-PH-K-S-LF--SN---3DModel-STEP-56544.STEP
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

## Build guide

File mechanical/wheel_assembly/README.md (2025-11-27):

# Wheel Assembly

The wheel assembly attaches the wheels to the motors and mounts the motors to the rest of the rocker-bogie suspension system that makes up the robot chassis. These are relatively simple to assemble.
 


__If you look carefully at the image above, you'll notice that the wheel assemblies are identical, instead of mirror images of each other. For example, notice that the U brackets for the corner wheels are facing different directions on the left and right sides. This is a defect in the OnShape model. When building your rover, you should make the wheel assemblies mirror images of each other - all the openings to the U channel should point to the rear of the rover.__

## [DollarHobbyz Traxxas Wheels only] Drilling the wheels

If you bought the DollarHobbyz Wheels, you will need to drill some holes through the plastic to allow attaching them to the hubs that fit onto the motor axes. If you have the smaller or bigger Wasteland Wheels from GoBilda, you can skip this step.

The wheel is normally meant to be mounted using one bolt through the middle of the rim. This will not work well in our case as the rover sees very high torque at the wheel and the one-bolt system would be difficult to attach to any part of our system without the wheel slipping. To attach more firmly, we will drill two holes on either side of the original hole where we will mount the motor hub clamp.

Drill at least 2 holes in the wheels such that they can be mounted to the [Hyper Hub](https://www.gobilda.com/1310-series-hyper-hub-8mm-rex-bore/) that attaches to the motor shaft. You'll want to make sure the holes you drill are centered, otherwise the wheel will wobble while driving. Once you've found where to drill the holes, consider using a center punch or small drill bit first before drilling to ensure your drill bit doesn't start 'wandering' before it locks into position. The distance from each hole center to the center of the wheel is  
$$\sqrt(8^2 + 8^2) \approx 11.3mm$$



You can download a [drill guide](https://cad.onshape.com/documents/4613de44a35fb12512683e12/w/c211c6182fe04b1f4dd7ceab/e/b6566fc4043fba7013bcec85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) designed to be laser-cut from 3mm acrylic and assembled as shown below to help you drill.

| drill guide | drill guide in use |
| --- | --- |
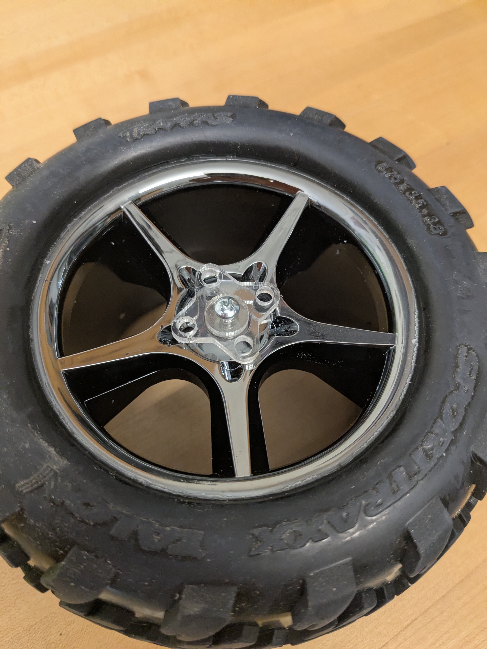
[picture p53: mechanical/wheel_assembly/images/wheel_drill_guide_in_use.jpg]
|  |  |

## Assembly

You will need all the parts in the [drive wheel assembly parts list](../../parts_list/README.md#Parts-for-drive-wheel-assembly).

### Assembling the base wheel mounts

Next, we will build the wheel assemblies which are divided into the middle wheels and corner wheel assemblies. We will build 6 identical base wheels and then add slightly more complexity onto 4 of those which will eventually become the corner wheels.

Attach the clamping mount and REX bore hub to the motor. We will adjust their positioning later.

## Four corner assemblies

Four of the six drive assemblies you just built will become the corner motors. That only requires two mechanical pieces along with some screws but we'll want to route the wiring through the extruded channel.

The result excluding wiring should look as follows:

| side view without wiring | one of two pairs of corner assemblies |
| --- | --- |
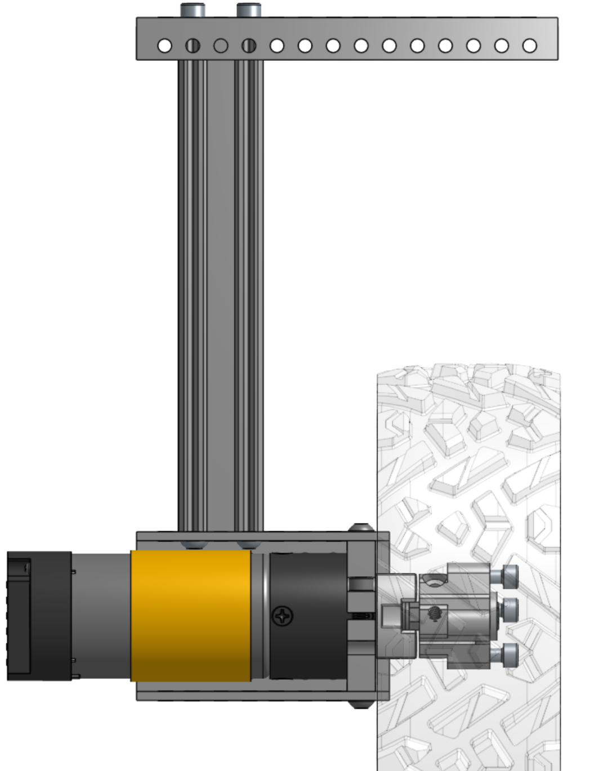
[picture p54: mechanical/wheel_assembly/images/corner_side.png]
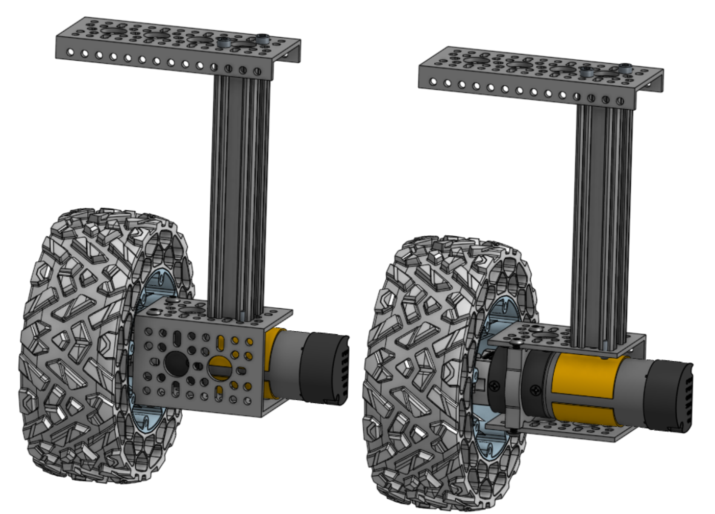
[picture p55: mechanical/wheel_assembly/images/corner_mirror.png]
|  |  |

Note that the sides of the rover are mirrored and so you'll be building 2 pairs of similar but not exactly the same subassemblies, as shown in the right image above.

Start by laying out the pieces for each corner so you end up with the 2 mirrored pairs. Install `2911-0014-0001` grommets at the top and bottom of the extruded aluminum goRail, to protect your wires as they go around the corner (not shown in the image below).  

Take the DuPont to 4-pin JST encoder pins you created in [wiring](../electrical/wiring/README.md) and route them through the top low-profile U-channel, the extruded aluminum goRail, and finally through the motor bracket. The DuPont connector should be at the top with the 4-pin JST connector at the bottom, ready to be connected to the motor encoder pins. 

Route the two motor power cables through the same parts in the opposite direction. Finally, screw the parts together using 3 or 4 M4x6mm button screws inside the U-channel and using 3 or 4 M4x8mm socket screws at the top. Don't tighten the screws too much yet as this will allow you to adjust wiring. Place a clamping motor mount on the end of the U-channel farthest from the goRail with 4 M4x6mm button screws.

Adjust the wiring so there is minimal wiring inside the channel. Make sure to protect your wiring from chafing or cutting from the sharp aluminum edges with split sleeve or other shielding! Be careful when adjusting wires so to not damage the plastic shielding and potentially create shorts.

### Optional Wiring Arrangement

There is not a lot of clearance between the U-channel and the motor for the wiring to pass through, especially when wrapping the cables in a sleeve. You can choose to cut a notch in the extruded aluminium goRail just above the U-channel, as shown below.

| goRail notched | corner assembly step 2 | corner assembled | 
| --- | --- | --- |
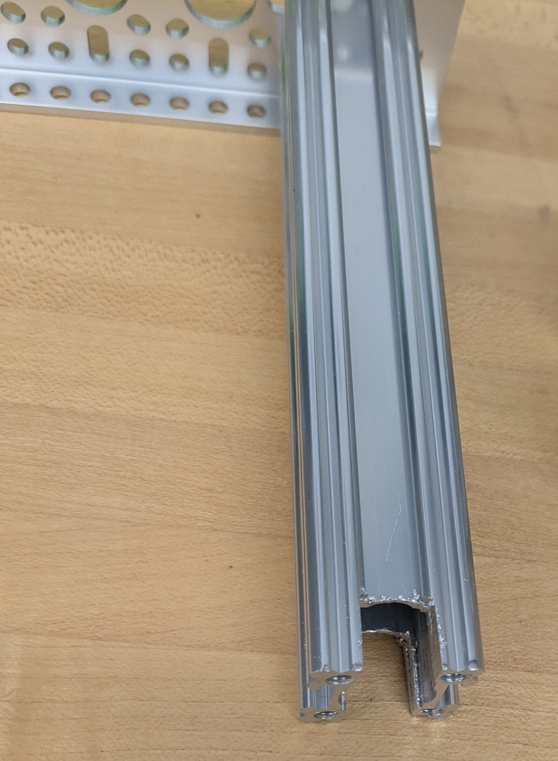
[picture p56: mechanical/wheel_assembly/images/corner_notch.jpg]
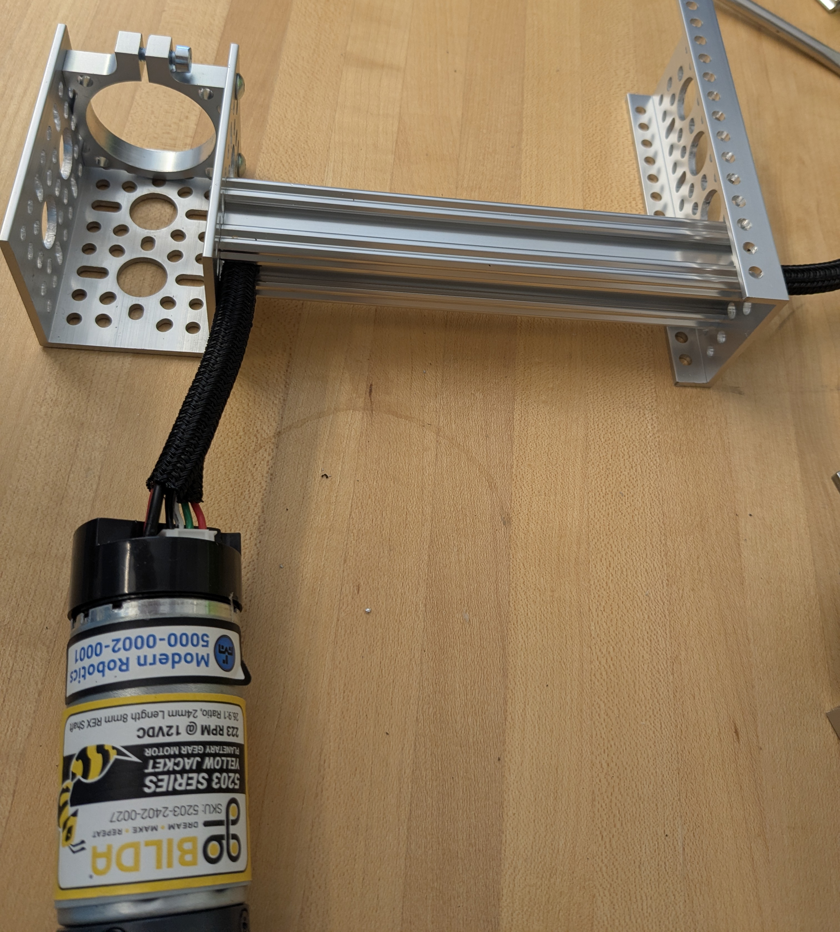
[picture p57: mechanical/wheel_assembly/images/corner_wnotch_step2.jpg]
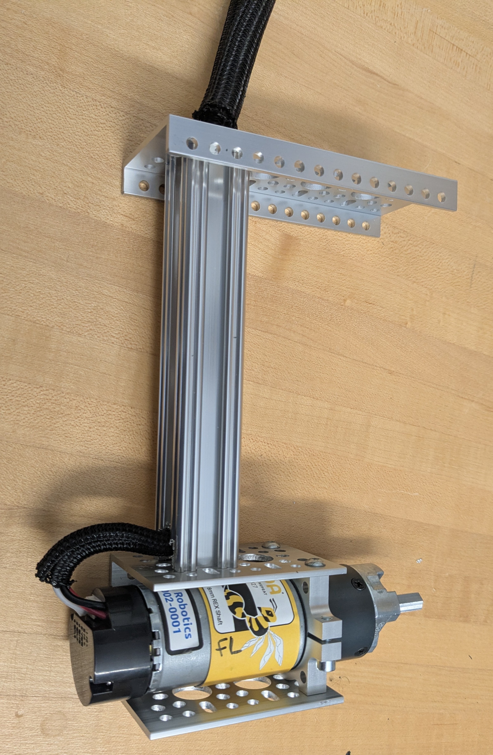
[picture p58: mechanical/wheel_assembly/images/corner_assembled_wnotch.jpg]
|  |  |  | 

Repeat this for the three other corner assemblies.

## Assembled corners
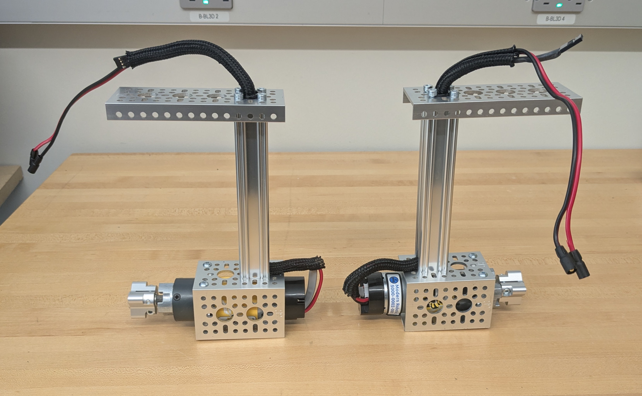
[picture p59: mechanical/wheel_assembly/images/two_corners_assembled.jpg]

Mirror image corner wheel assemblies without the wheels attached yet. Wiring with sleeves is visible.

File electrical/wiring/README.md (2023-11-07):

# Wiring

The wiring is what connects each of the 10 motors to the motor board carrying power and data. While creating the wiring requires a bit of patience, it's important that it's done properly so there's a consistent connection to the motors. Loose wires mean that the rover will not work as well or at all. Mechanical assemblies are more easily repaired than faulty wiring. If you have all parts ready to go, it could take between 2 and 5 hours to complete, depending on your skill level with crimping.

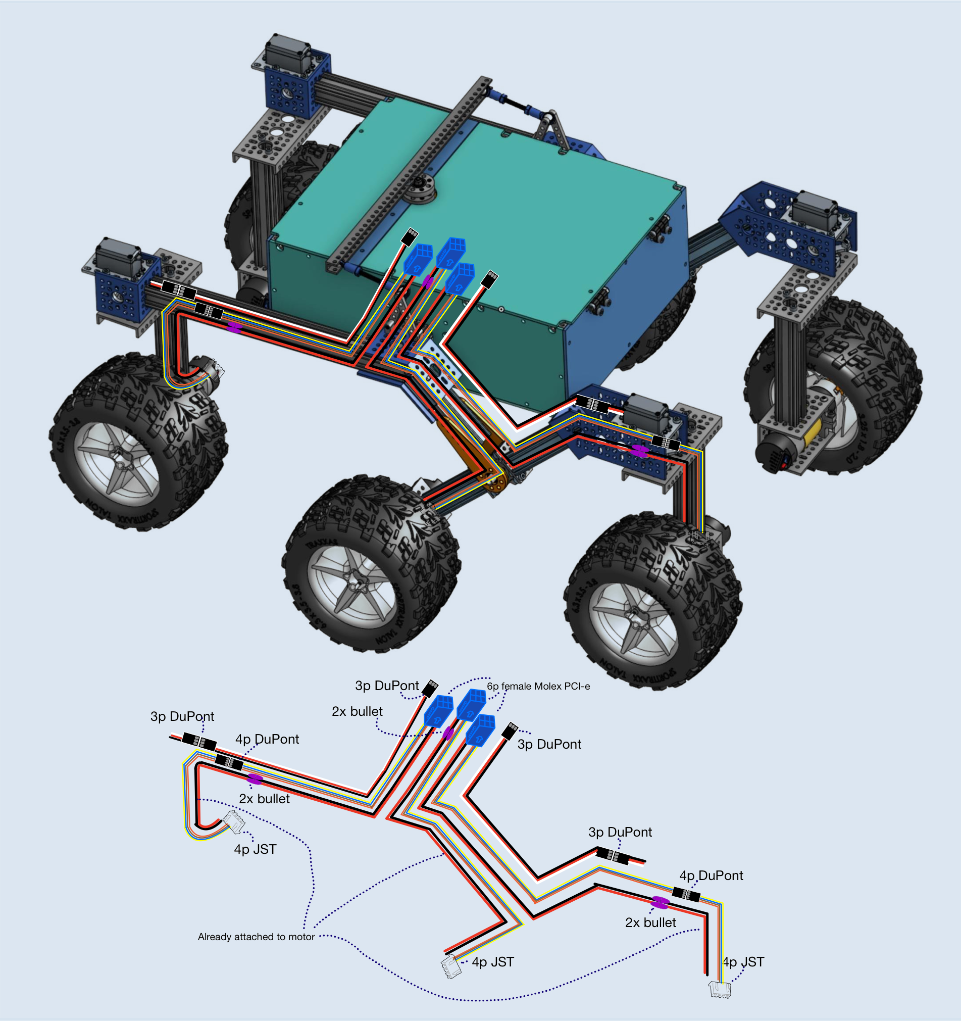
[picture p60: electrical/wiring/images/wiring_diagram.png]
wiring diagram

Wiring diagram for one side of the rover. The other side is identical.

Harness diagrams further below were generated with [WireViz](https://github.com/wireviz/WireViz/) and can be re-generated with the *generateHarness.bat/.sh* scripts.

>**Some notes on terminology:**

>***Wiring harness*** *(also called **cable harness** or **wire assembly**)*: the collective term for all the wiring and cables that are run through a system to connect power sources, sensors, data lines, etc. In the case of the rover, this means the cables that feed power to the motors, the control signals to the servos, and the encoder data back to the control boards. 

>***Cable***: A group of wires/conductors, usually with an outer sheath.

>***Wire***: A single conductor, solid or stranded core, of any gauge.

## Overview

We will be building several cables, all visualized in the above diagram. Make sure you have all wire types and connectors and understand the routing of the cabling as it will save you time down the line.

1. **4x**: JST female 4pin &harr; Dupont female 4pin (**connects to (2)**)
   * We'll use these to connect the drive motor encoders at the corners to the top of each corner
   * Having an intermediate connection allows us to swap out motors, perform testing, and route the wires through the parts much easier.
   * These are all of length **35cm** (all lengths excluding connector length)
   * You can also buy 4 premade cables [from Gobilda](https://www.gobilda.com/encoder-breakout-cable-4-pos-jst-xh-mh-fc-to-4-x-1-pos-tjc8-mh-fc-300mm-length/). They are a bit shorter so you can make the wires in Step (2) 5cm longer without any issue.
2. **4x**: Dupont male 4pin &harr; 4-pins of female Molex connectors
   * These will connect the drive motor encoders for each corner to the PCB through the rocker-bogie. The DuPont male side will plug into (1)
   * The Molex connectors will be inserted in the 6-pin PCI-E connector
   * 2 of these should be **52cm** long for the front, the other 2 should be **45cm** long for the back
3. **2x**: JST female 4pin &harr; 4-pins of female Molex connectors
   * These will connect the drive motor encoders for the two middle wheels to the PCB
   * The Molex connectors will be inserted in the 6-pin PCI-E connector that plugs into the PCB
   * These will both be **53cm** long
4. **6x**: 2-pin female bullet connector &harr; 2-pin female Molex connector
   * These will connect the two drive motor power supplies (M+ and M-) to the PCB
   * 2 of these are **2cm** long for the middle wheels
   * 2 of these are **53cm** long for the front wheels
   * 2 of these are **40cm** long for the back wheels
5. **4x**: Dupont male 3pin &harr; DuPont female 3pin connectors
   * These will connect the corner servo motors to the PCB
   * 2 of these are **53cm** long for the front corner servos
   * 2 of these are **35cm** long for the back corner servos

In total: 24 JST female crimps, 6 JST female connectors, 36 female DuPont crimps, 6 MH-FC PCI-E connectors, 28 male DuPont crimps, 16 female DuPont crimps, 4 3pin DuPont connectors, 8 4pin DuPont connectors, and 12x bullet connectors+crimps.

The harness diagrams in this README also contain an integrated bill-of-materials (BOM) for each cable so you can organize the parts appropriately.

> **Tip**: Rather than crimp each wire yourself, you can buy premade connectors, cut the wires, and then solder them to the other side. For soldering using a heat gun, you could get something like the following: [heat gun solder seal wire](https://www.amazon.com/Amliber-Connectors-Solderstick-Waterproof-Electrical/dp/B0BXKHBDFB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). This depends on your preferences. When using premade connectors, be extra careful of the pinouts so you connect the correct wire ends together.

> **Tip**: For the thinner (AWG20 and AWG22) wiring we strongly recommend using ribbon cable (where each wire strand is attached to the next) to keep wires clean and strong. Alternatively you can twist the wires which also helps reduce interference from electrical noise.

## Cut the wires to length

We want to be consistent with the color coding of your wires so we can troubleshoot easier. For example M+ (motor positive) should always be red and M- black for all drive motors. We'll also use the same colored wires for all encoders. We'll add one centimeter to each piece of wire for inserting into the connectors.

As can be seen on the diagram, we'll have three color coded types:

* *servo wire*: white, red, and black for the servo motors. The servo motors already have wires in these colors. wire gauge: 20AWG.
  * Cut 2 pieces of 53+1=54cm
  * 2 pieces of 36cm
* *encoder wire*: 4 colors of your choice for the drive motor encoders (in diagram: yellow, blue, brown, orange). wire gauge: 22AWG.
  *  Cut 4 pieces of length 35+1=36cm
  *  2 pieces of 53cm
  *  2 pieces of 46cm
  *  2 pieces of 54cm
* *power wire* black and red for the drive motor power. wire gauge: 18AWG.
  * Cut 2 pieces (of red and black wire) of 2+1=3cm
  * 2 pieces of 54cm
  * 2 pieces of 41cm

Optional but recommended: put two pieces of heat shrink on each set of wires. This allows you to securely remove a connection without accidentally stressing one wire/crimp too much. It also prevents the wires from detaching from one another.

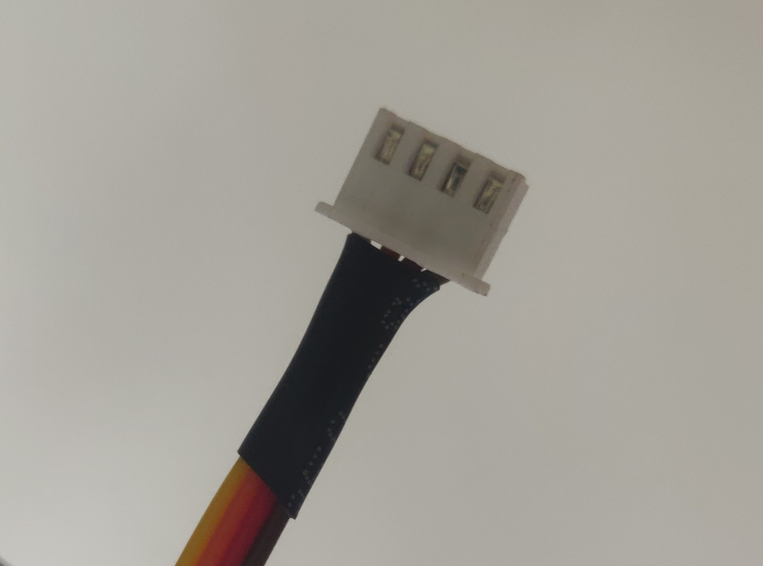
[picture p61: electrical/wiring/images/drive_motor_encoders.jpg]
finished JST connectors for the drive motor encoders

Heat shrink around a female 4p JST connector.

## Step (1) 4x: JST female 4pin &harr; Dupont female 4pin

Use the 4 pieces of 36cm *encoder wire*. Separate the wire ends from the ribbon cable so you can attach crimps to each wire. Using a wire stripper, remove about 3mm of wire protector from each wire. On one side of each 4-wire cable, use a crimping tool to attach a female JST crimp to each wire.

> **Tip**: There are many great resources online to learn how to crimp effectively. Put the crimp into the crimping tool and lightly clamp down so the crimp doesn't fall out. Then inside the wire end and complete the crimp. When you have completed the crimp, give it a solid tug to test if it's properly attached. Loose crimps will backfire later!

On the other side of the cable, you will attach 4 Dupont female crimps. You now have one of 4 crimped wires, so repeat the process for the 3 other wires.

Now we'll insert each crimped cable into the appropriate connectors. Start by writing the pinout on each of the connectors for easy troubleshooting using a sharpie: B, A, G, 5 for channel B, channel A, ground, and +5V respectively. Copy over the annotations from the images below to your connectors, paying close attention to the orientation of each connector. Use the harness diagram below as a guide to make sure that each connector is in the right position in its housing. 

> **Tip**: On single row connectors like the JST-XH and the DuPont, there is usually a mark on the connector housing (like a triangle or a cutout) that indicates position 1. These are more visible in the harness diagrams.

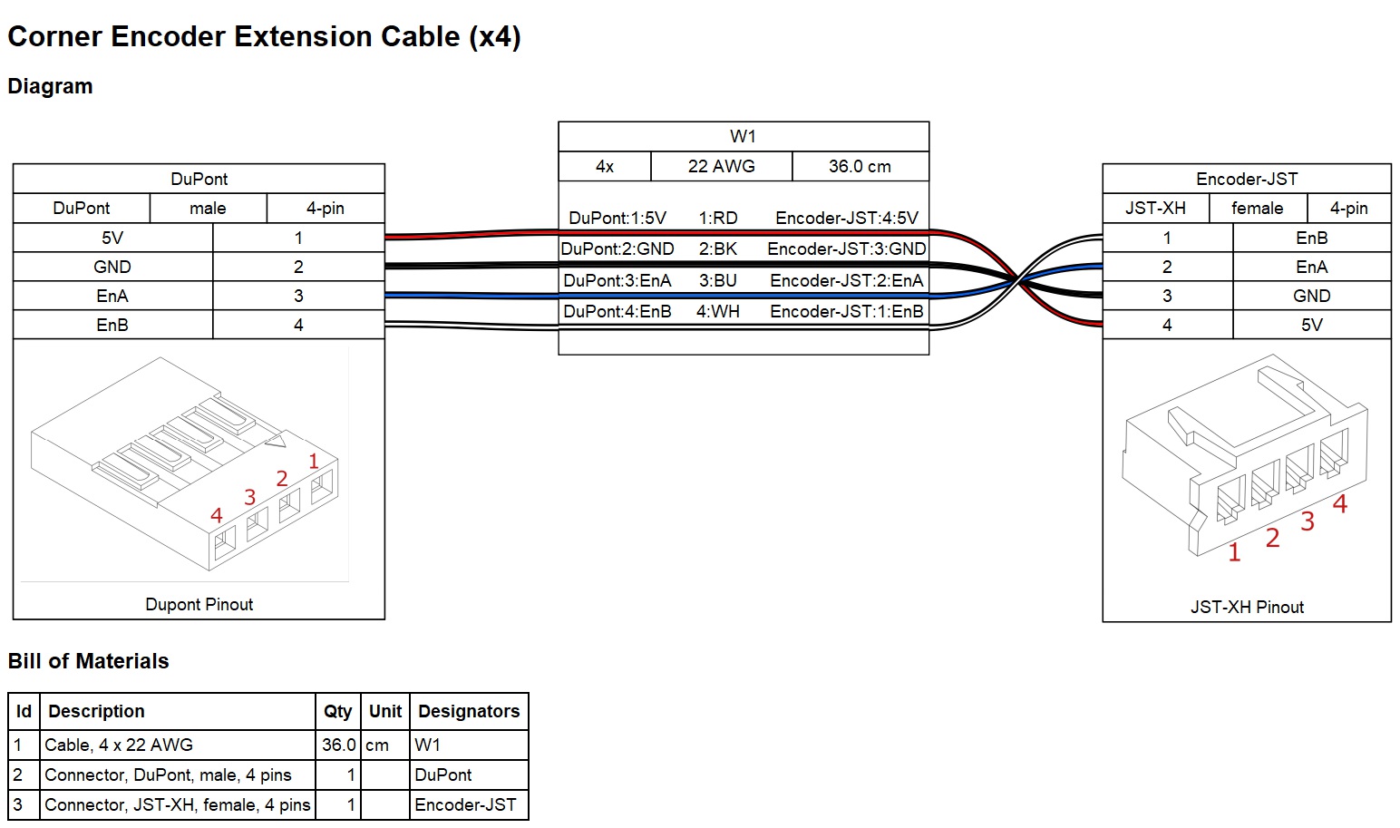
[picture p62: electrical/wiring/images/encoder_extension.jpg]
Encoder Extension Harness Diagram


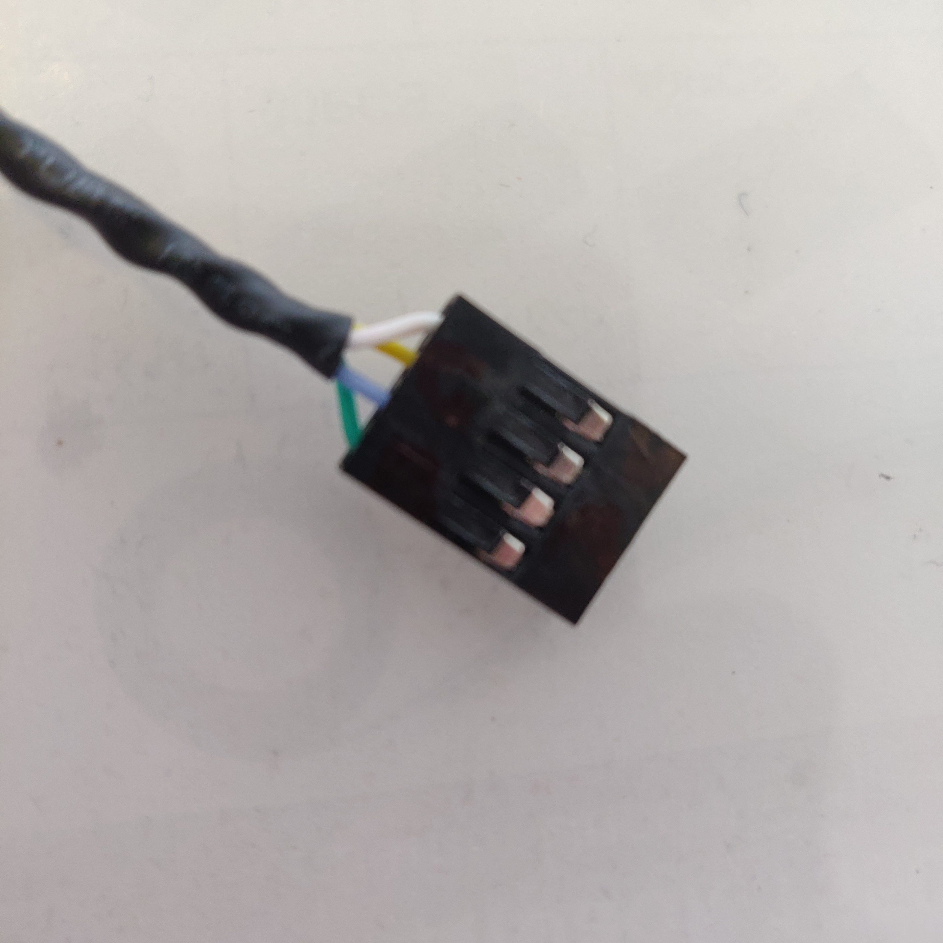
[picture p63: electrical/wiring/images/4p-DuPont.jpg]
DuPont 4pin connector
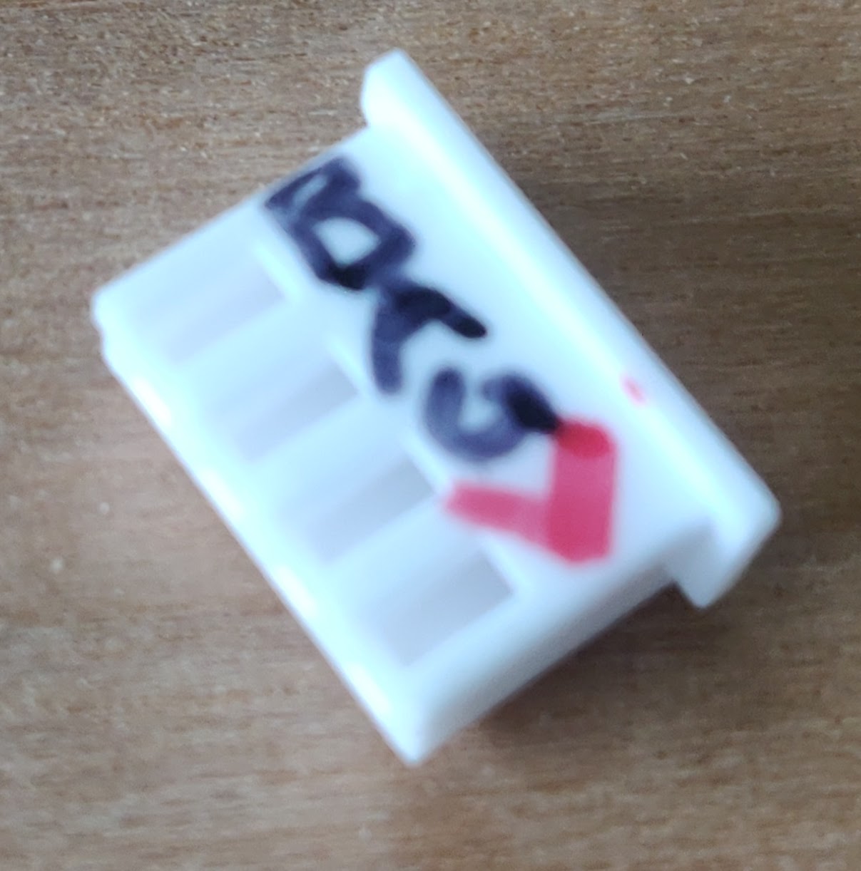
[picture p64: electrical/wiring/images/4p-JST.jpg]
JST 4pin connector
|  |  |
| --- | --- |
| Dupont 4p connector. From top to bottom: VCC/5V (white) &rarr; GND (yellow) &rarr; enA (blue) &rarr; enB (green) | female 4p JST connector. From top to bottom: enB &rarr; enA &rarr; GND &rarr; VCC/5V |
Finally insert the crimps into the connectors. Repeat for all cables, using the same coloring for each connector hole. If you used heat shrink, use a heat gun to secure the connection.

> **Tip**: When you finish a cable, use the connection testing setting on your multimeter so verify that your cables work. This will save you a lot of time debugging in the future!

## Step (2) 4x: Dupont male 4pin &harr; 4-pins of female Molex connectors

These cables will connect the Dupont side of the cables we made in step (1) to the PCB via a 6pin PCI-E connector with female Molex connectors.

This process is very similar to the steps we did in (1), except we'll use male DuPont crimps on one side and female Molex crimps on the other side. For the male DuPont connector side, make sure the wires match the female DuPont connector you made in Step (1).

Grab the 2 pieces of **encoder wire** of 53cm and 2 pieces of 46cm and prepare the wire ends for crimping. Attach the crimps to each wire and repeat for each set of wires.
As before, mark the connectors as in the images below, then insert the wires into the connectors. 

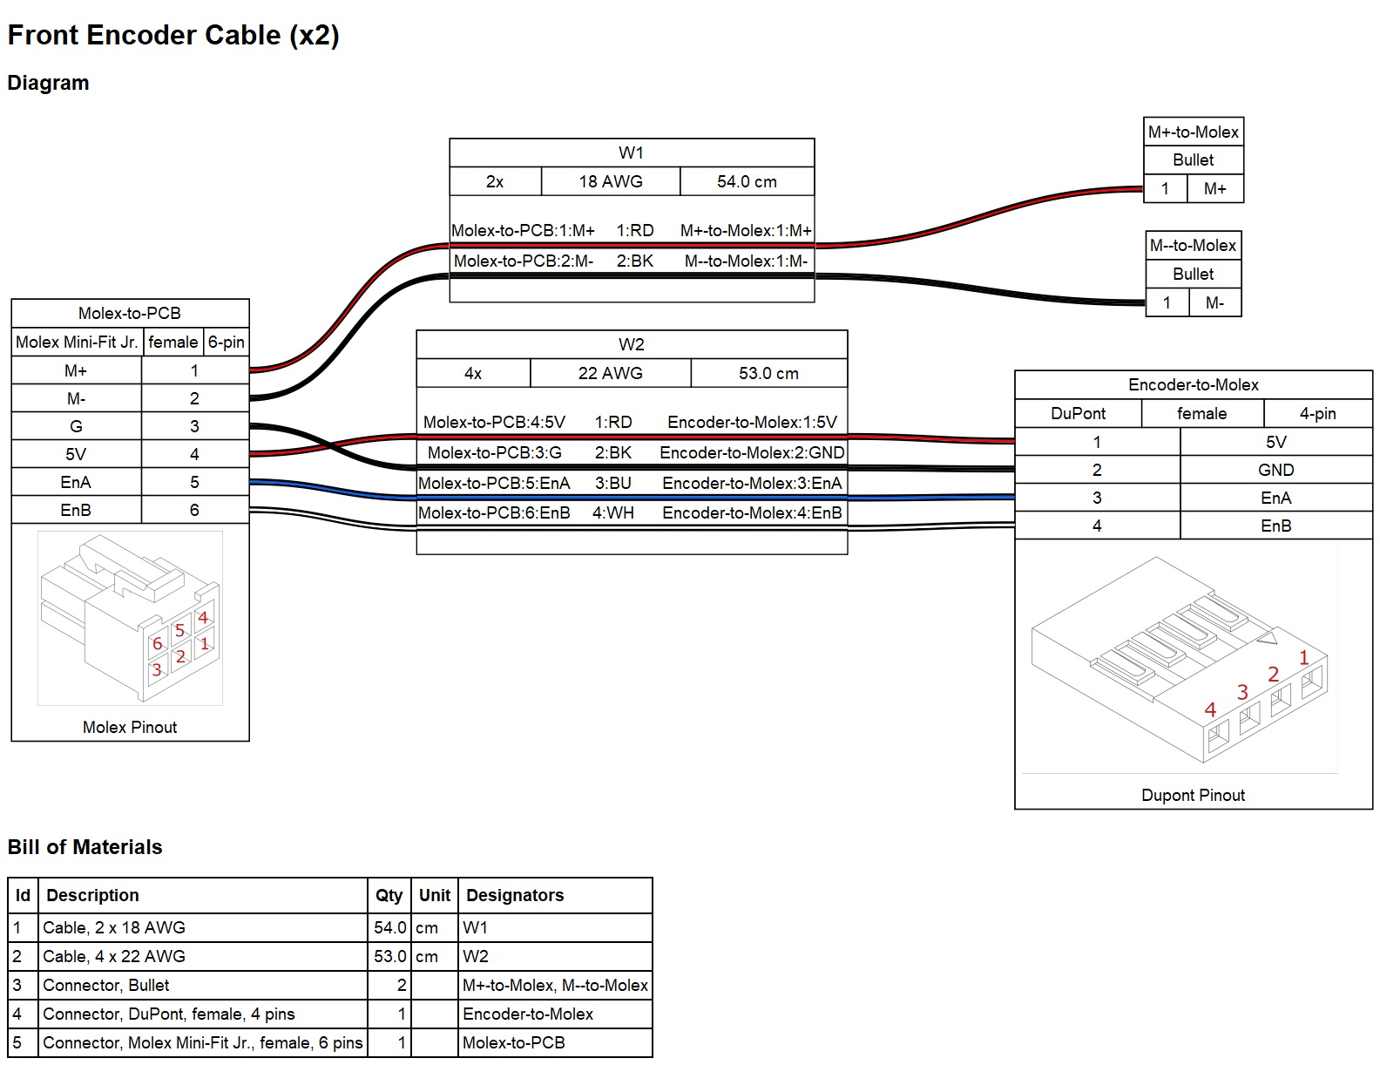
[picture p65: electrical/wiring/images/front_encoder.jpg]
Front Encoder Harness Diagram

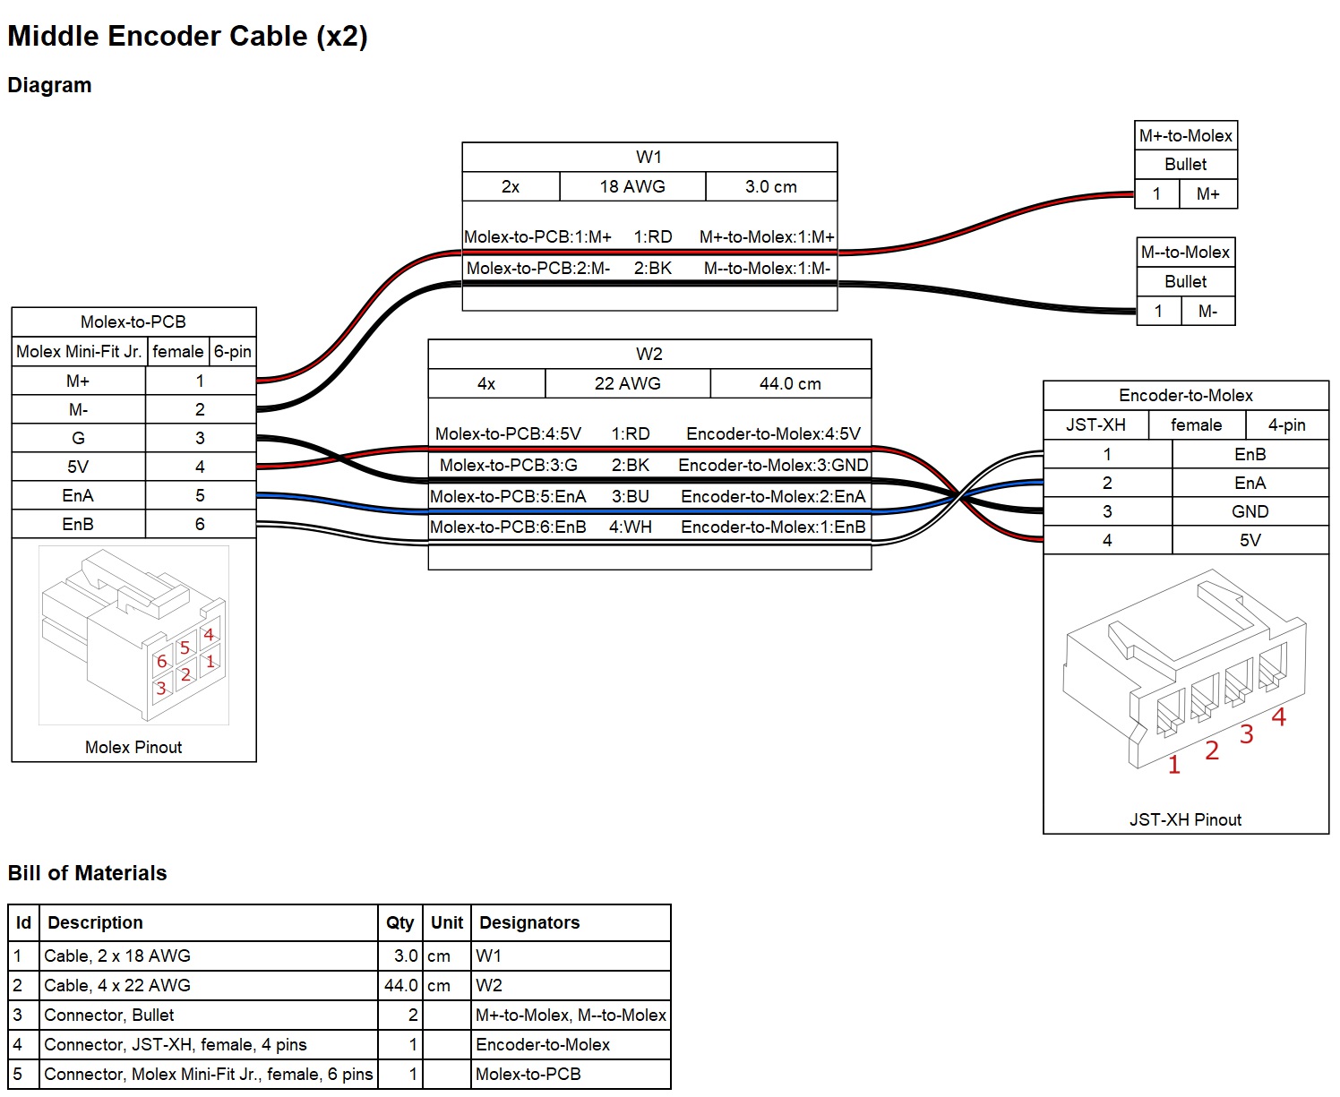
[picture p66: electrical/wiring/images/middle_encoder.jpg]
Middle Encoder Harness Diagram

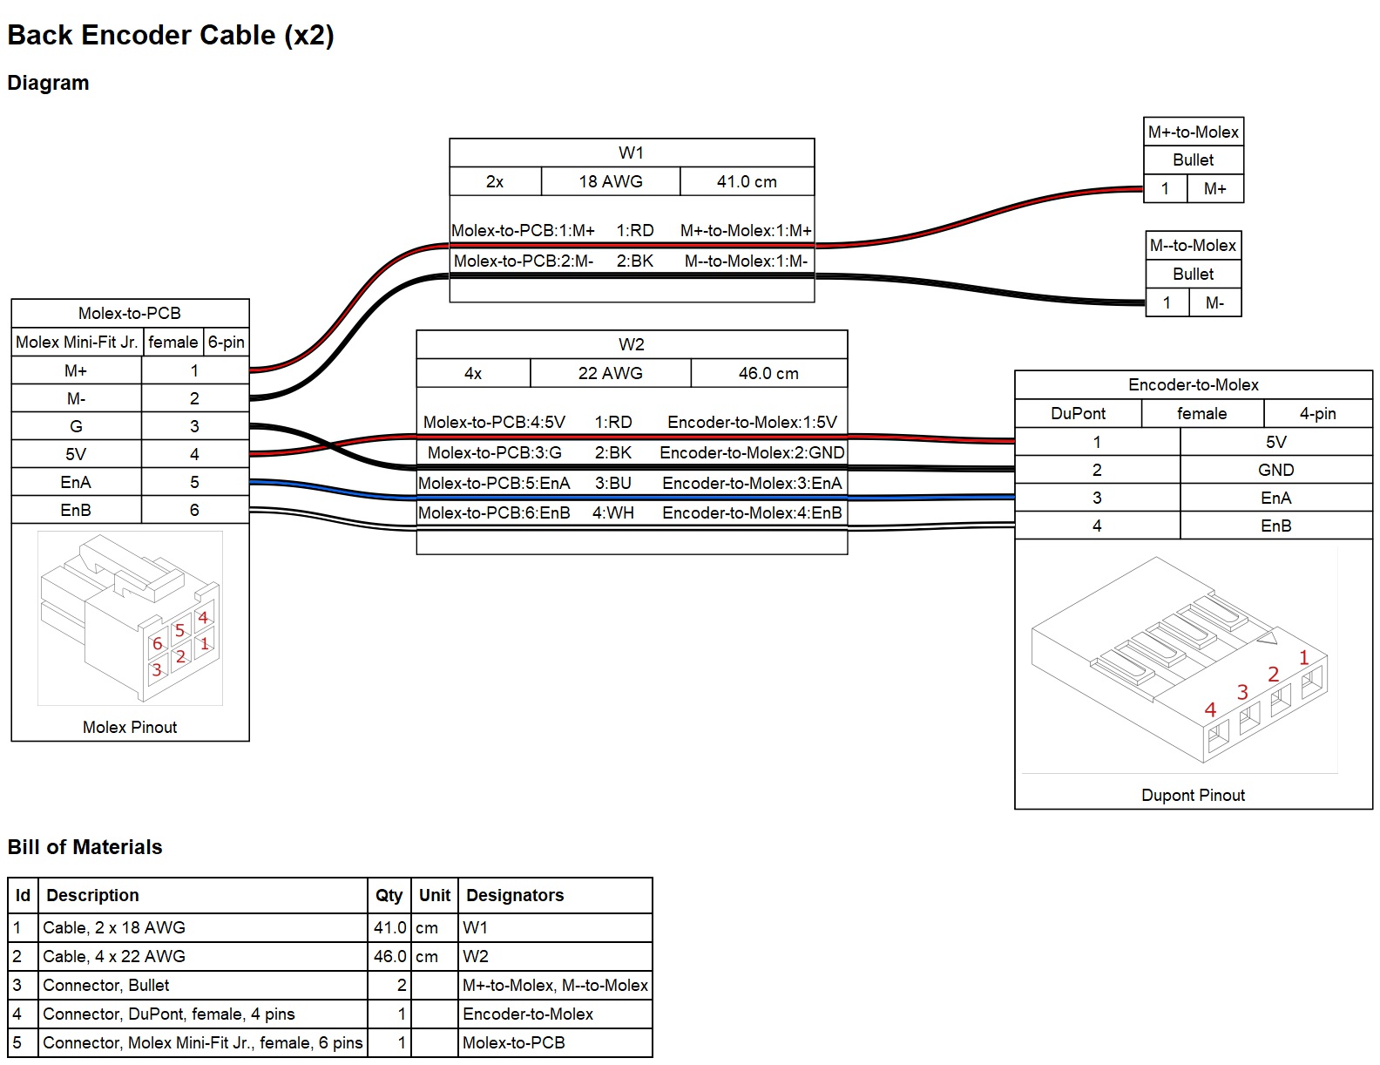
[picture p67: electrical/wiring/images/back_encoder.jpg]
Back Encoder Harness Diagram


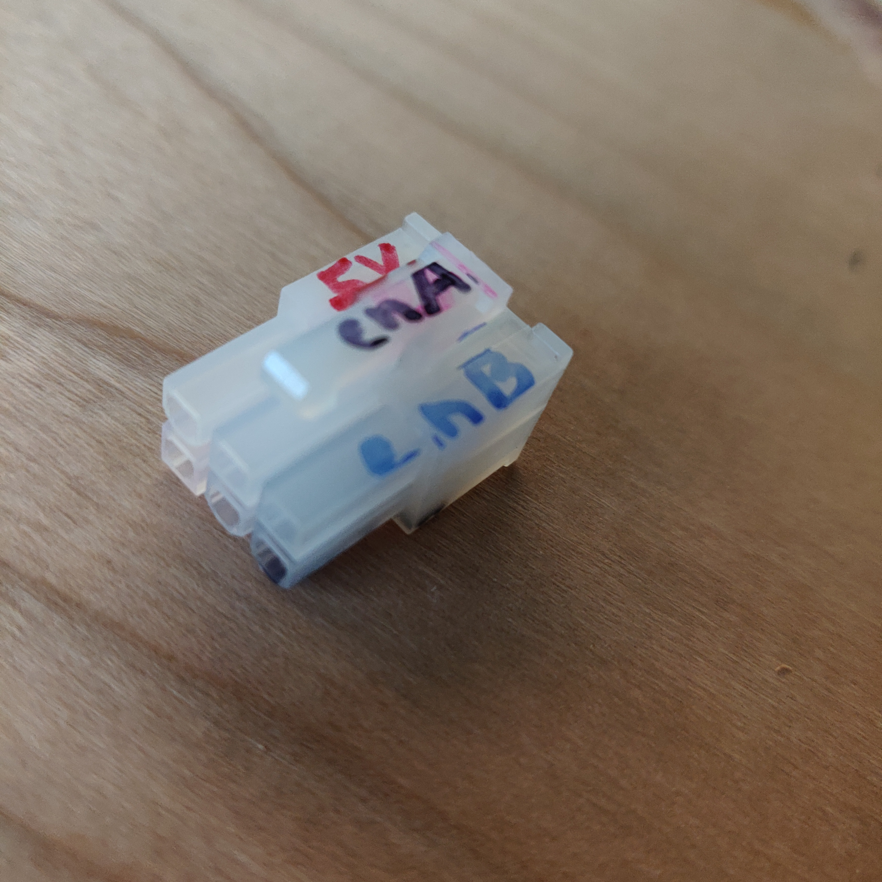
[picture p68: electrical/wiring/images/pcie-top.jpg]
Molex PCI-E connector top
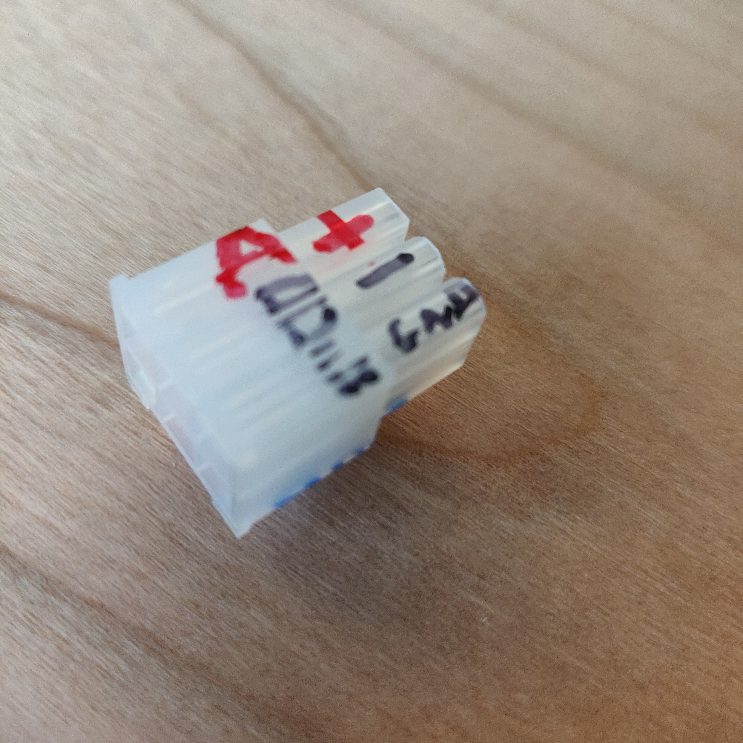
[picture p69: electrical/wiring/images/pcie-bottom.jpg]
Molex PCI-E connector bottom
|  |  |
| --- | --- |
| Top of PCI-E connector. 5V &rarr; enA &rarr; enB | bottom of PCI-E connector. M+/A &rarr; Mi/B &rarr; GND |

Mark the PCI-E connector with on each of the two longer cables with 'F' for front and the two connectors attached to the shorter cables with 'B' for back. This will prevent inserting the cables into the wrong slot on the PCB since all cables arrive into the body through the same goRail. The remaining two slots for M+ (A) and M- (B) on each of these connectors will be filled in step (4).

## Step (3) 2x: JST female 4pin &harr; 4-pins of female Molex connectors

These 2 wires that connect the drive motor encoders for the middle wheels to the PCB directly are a combination of cables (1) and (2), skipping the intermediate DuPont connector. Mark the PCI-E connector for each of the two cables with 'M' for middle.

## Step (4) 6x: 2-pin female bullet connector &harr; 2x female Molex connector

Grab the 6 pairs of red and black *power wire*. On each wire side attach a female bullet connector on one side and a female Molex connector on the other. 

* For the two shortest cables you made, insert the Molex end into the open slots on the middle PCI-E connector you assembled in Step (3).
* For the two longest cables you made, insert the Molex end into the open slots on the front PCI-E connector you assembled in Step (2).
* For the two mid-length cables you made, insert the Molex end into the open slots on the back PCI-E connector you assembled in Step (2).

You now how all the wiring completed for the drive motors!

## Step (5) 4x: Dupont male 3pin &harr; DuPont female 3pin connectors

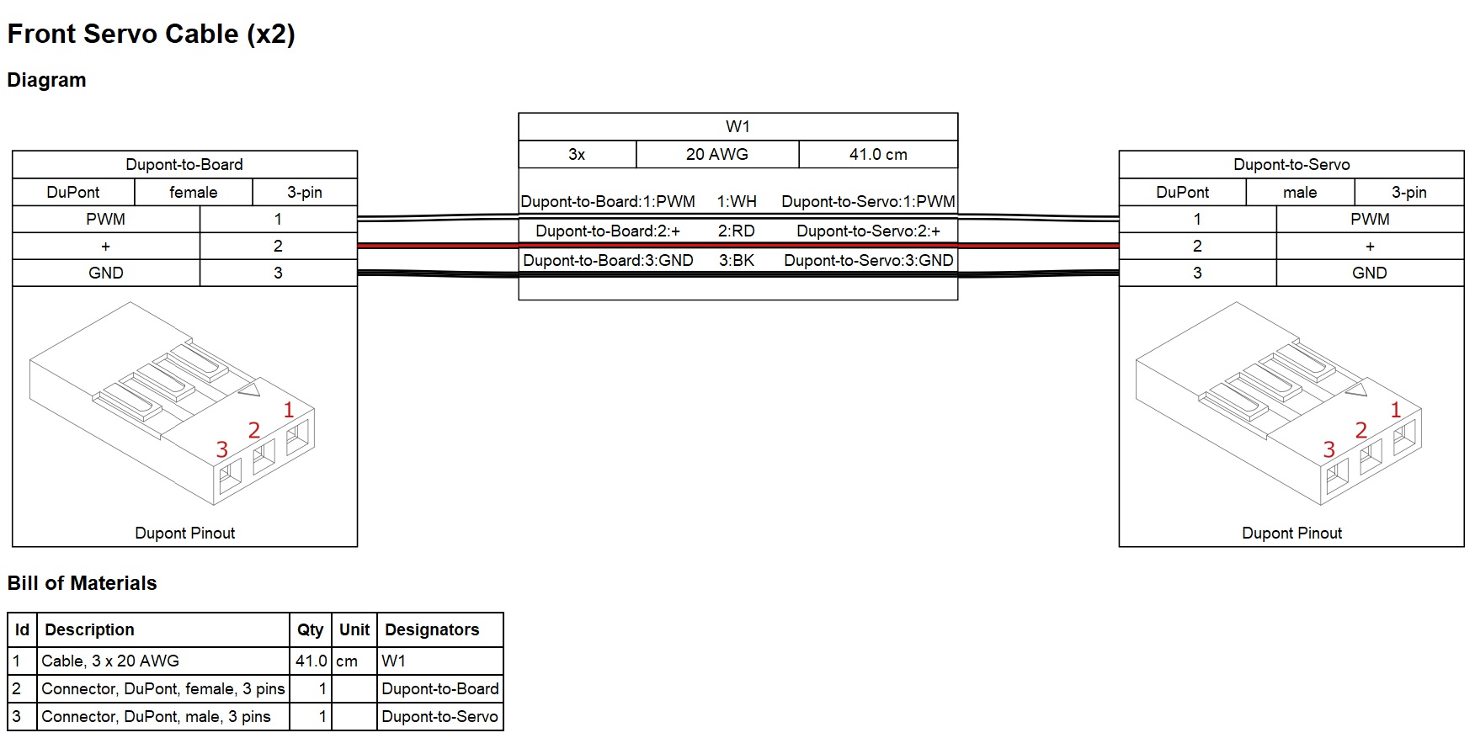
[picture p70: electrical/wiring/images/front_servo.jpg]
Front Servo Harness

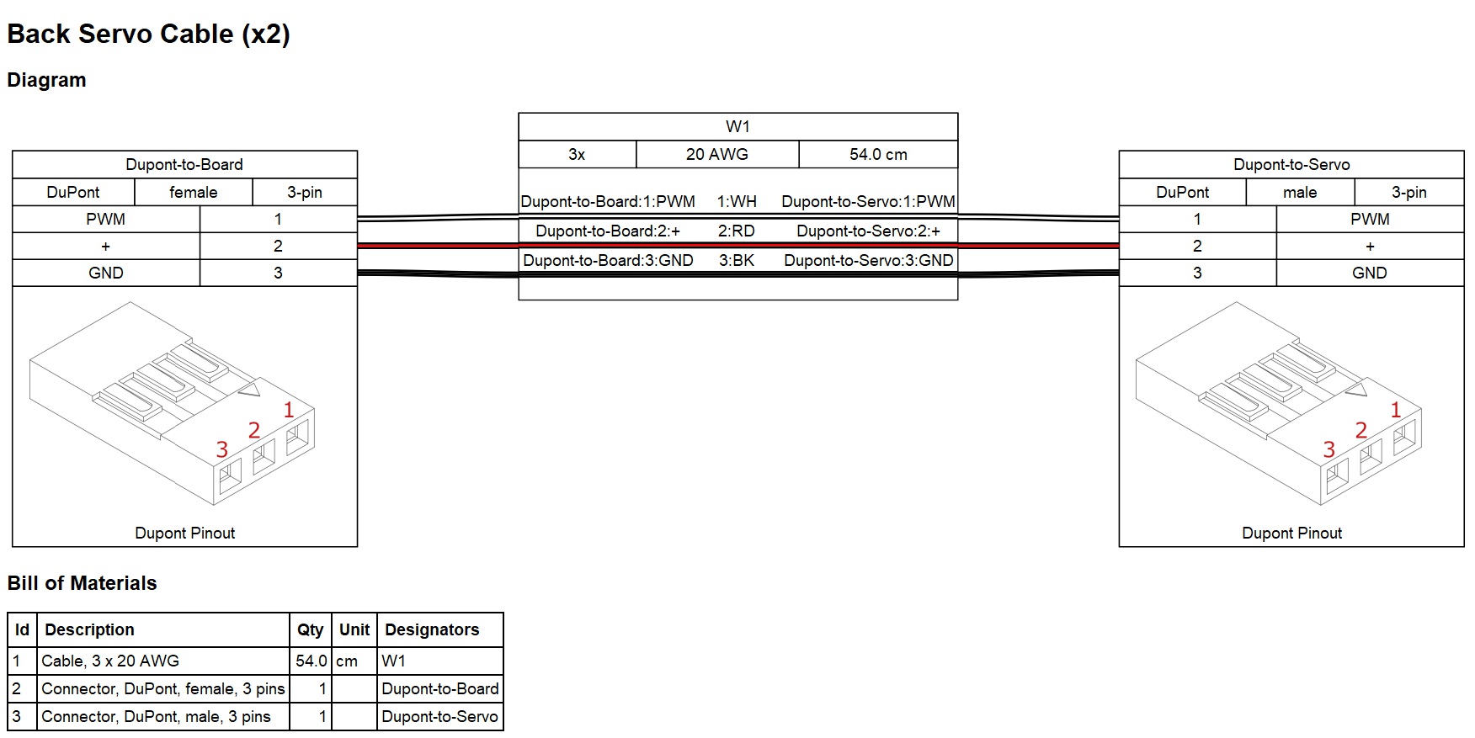
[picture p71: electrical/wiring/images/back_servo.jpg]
Back Servo Harness


All that's left are the servo ribbon cables. The red and black wires are (+) and (-) voltage to the motor and the white cable carries the PWM signal to command the on-board controller to command the motor to the desired angle, using the built-in absolute encoder. The PCB header pins for the servo motors are wired in the same order (PWM, (+), (-)) so we're essentially building an extension cord in this step. One one side you'll be using male DuPont crimps while on the other you'll use female DuPont crimps. The connectors for both sides are identical.

You should now have 12 finished cable assemblies. Congratulations! Don't forget to make sure each connection is solid and tested before moving on.

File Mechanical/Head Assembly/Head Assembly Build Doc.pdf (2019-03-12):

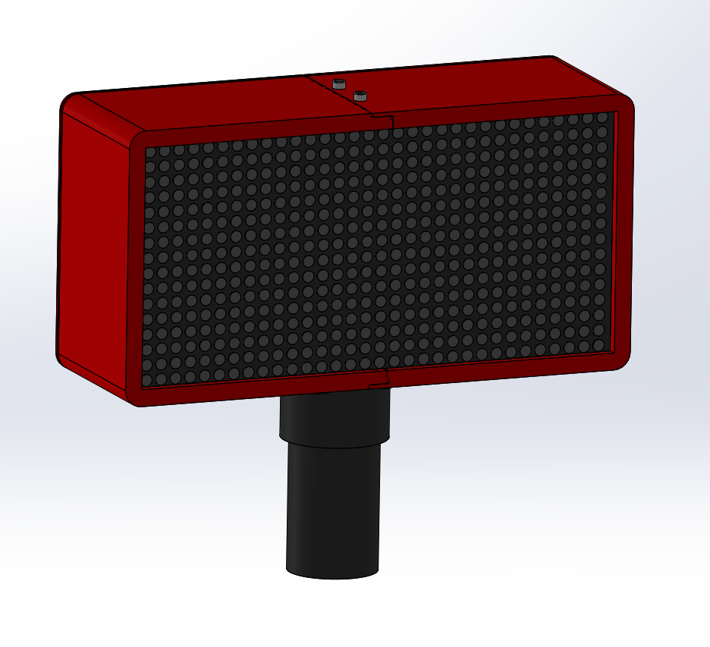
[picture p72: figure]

# Open Source Rover: Head Assembly Instructions

## Authors: Michael Cox, Eric Junkins, Olivia Lofaro

Reference herein to any specific commercial product, process, or service by trade name, trademark, manu-

facturer, or otherwise, does not constitute or imply its endorsement by the United States Government or the

Jet Propulsion Laboratory, California Institute of Technology.

c 2018 California Institute of Technology.

Government sponsorship acknowledged.

1

CONTENTS | CONTENTS

## Contents

1 3D printing | 3
2 Machining/Fabrication | 4
3 Mechanical Assembly | 5
Open Source Rover Mechanical Assembly Manual | Page 2

1 3D PRINTING

## 1 3D printing

There are a few components that need to be 3D printed to make the head assembly. You can

find the STL files necessary for these prints in the Mechanical/Head Assembly/3D Printed

Parts folder of the repository. Based on difficulties we’ve seen with printing these pieces,

we’ve also included a few different orientations of ”printing pads” to help with thermal

contraction as shown in Figure 1. These pads help hold the corners down and reduce the

warping of the pieces.

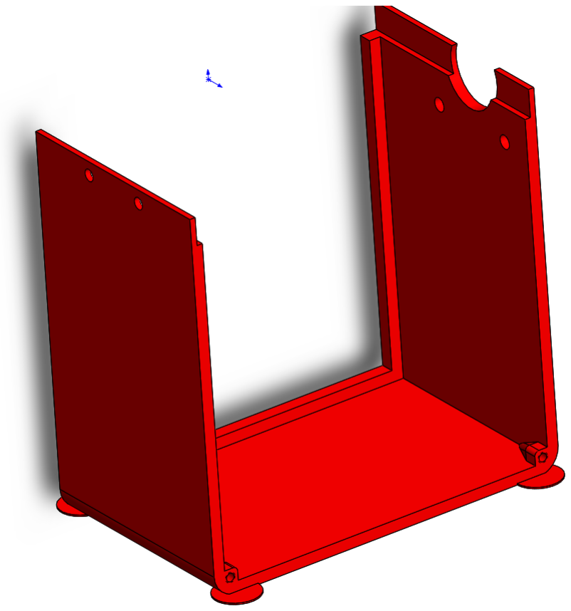
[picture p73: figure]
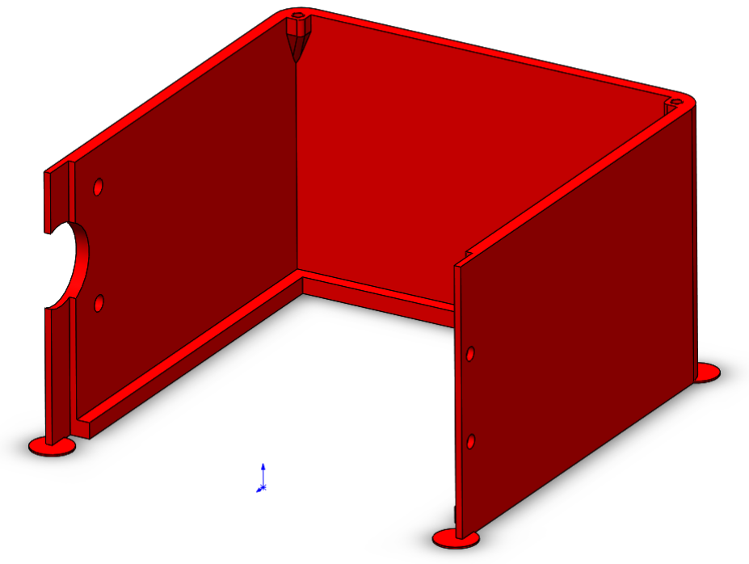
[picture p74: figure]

Figure 1: Printing Pads

If you do not have a 3D printer there are a number of online 3D printing services

available, an example of which can be found at:

- https://www.makexyz.com/

(If you decide to use a 3D printing service, we recommend sending them the files without

the printing pads.)

Open Source Rover Mechanical Assembly Manual | Page 3

### 2 MACHINING/FABRICATION

## 2 Machining/Fabrication

### 2.1 Cutting the PVC Pipe

Table 1: Parts/Tools Necessary

Item | Ref | Qty | Image | Item | Ref | Qty | Image
2” PCV Pipe | S29 | 1 | | Vice or V-Clamps | D8
HackSaw or Bandsaw | D4

Take the PVC pipe S29 (this will be the ”neck” of the rover) and cut it to your desired

length. For reference, we cut our ”neck” PVC pipe to be roughly 6 inches long.

Open Source Rover Mechanical Assembly Manual | Page 4

### 3 MECHANICAL ASSEMBLY

## 3 Mechanical Assembly

Table 2: Parts/Tools Necessary

Item | Ref | Qty | Image | Item | Ref | Qty | Image
Head Left Back | S33A | 1 | | #6-32x3/8” Button Head Screw | B2 | 4
Head Right Back | S33C | 1 | | #4-40x1/4” Button Head Screw | B8 | 12
Head Left Side | S33B | 1 | | #4-40 Locking Hex Nut | B12 | 4
Head Right Side | S33D | 1 | | LED Matrix | E8 | 1
Bore Clamping Hub for 1” PVC | S24 | 1 | | Allen Key Set | D2
PVC Pipe (Modified) | S29A | 1 | | 5/16” Wrench | D1
Logic Shifter PCB | E11 | 1
1. Insert the LED matrix into the head: Start by taking the LED Matrix E8 and

inserting it on the ledges in the left and right sides of the 3D printed head. Screw

together the two sides of the head using screws B8.

1

1The size of the holes should be such that you can use a hex key to ”thread” the 3D printed holes. If it is too tight, you can use a drill/file to very slightly open up the hole

Open Source Rover Mechanical Assembly Manual | Page 5

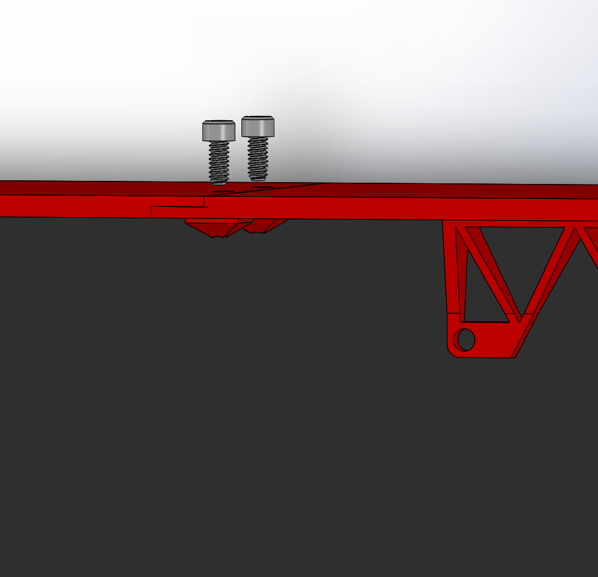
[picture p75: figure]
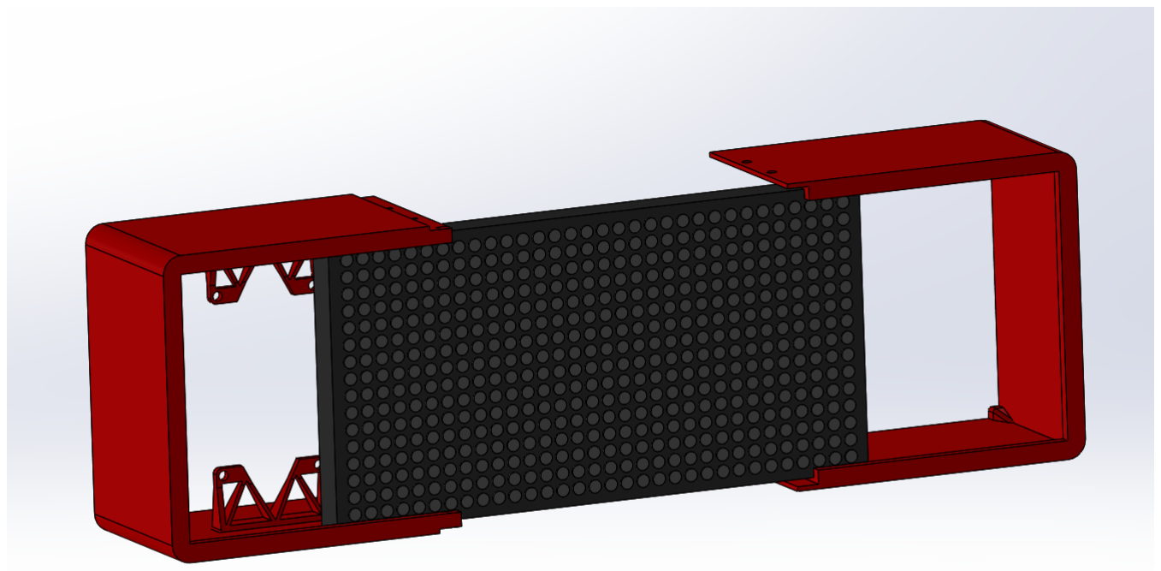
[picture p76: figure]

Figure 2: Inserting LED Matrix

2. Attach the PVC Clamping Hub: Attach the 1 Inch PVC Clamping Hub S24 to

the bottom of the head using screws B2.

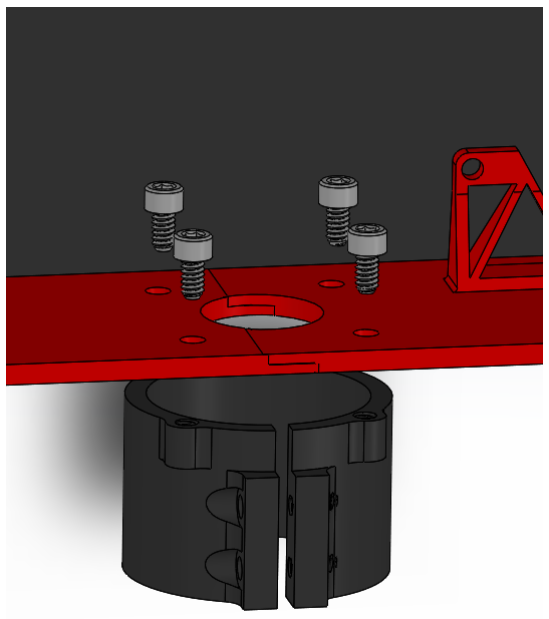
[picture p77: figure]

Figure 3: Attach the PVC Clamping Hub

3. Mounting the Logic Shifter PCB: Attach the Logic Shifter PCB to the support
Open Source Rover Mechanical Assembly Manual | Page 6

structure in the 3D printed head using screws B8 and hex nuts B12.

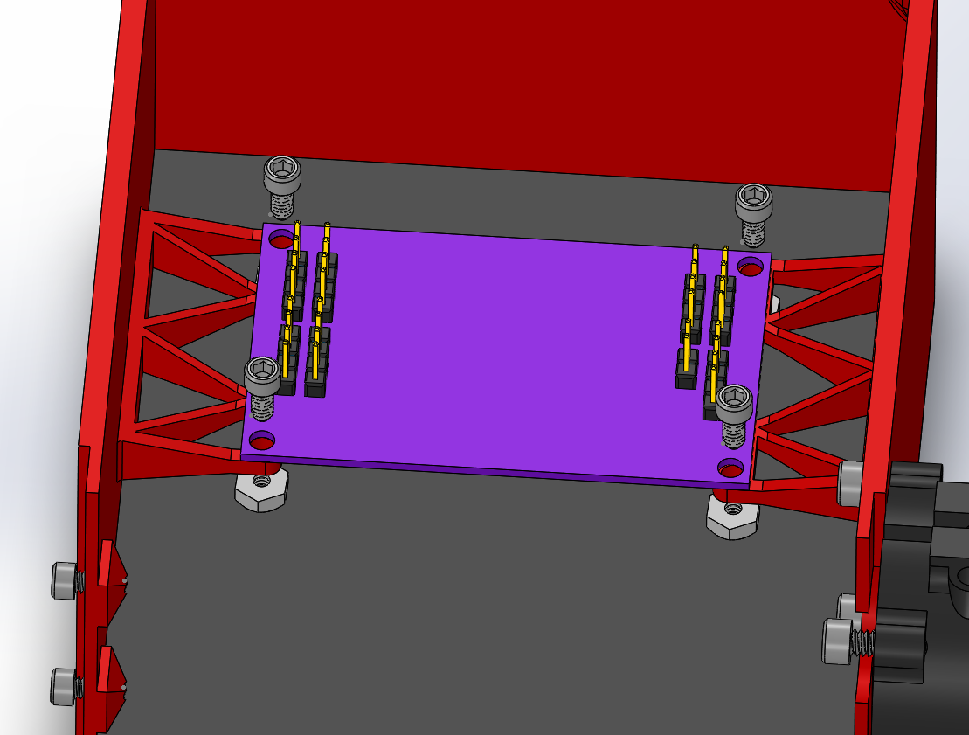
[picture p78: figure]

Figure 4: Mounting the Logic Shifter PCB

4. Connecting to back plane: Attach the two back pieces together using screws B8.

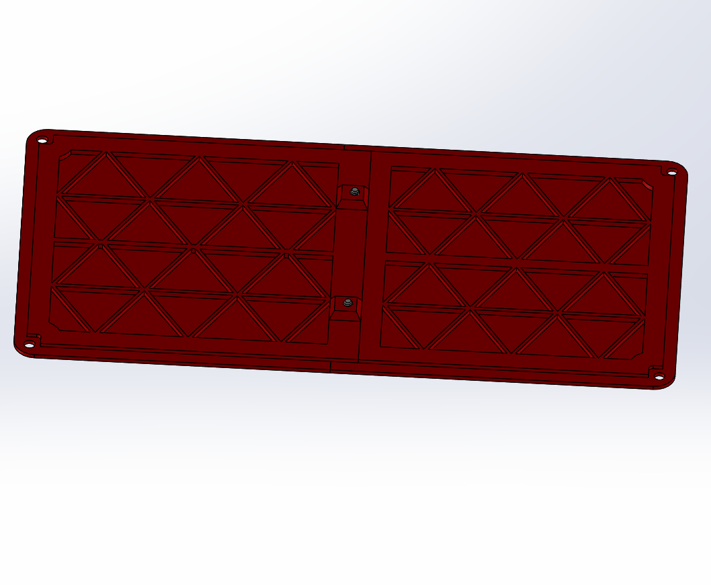
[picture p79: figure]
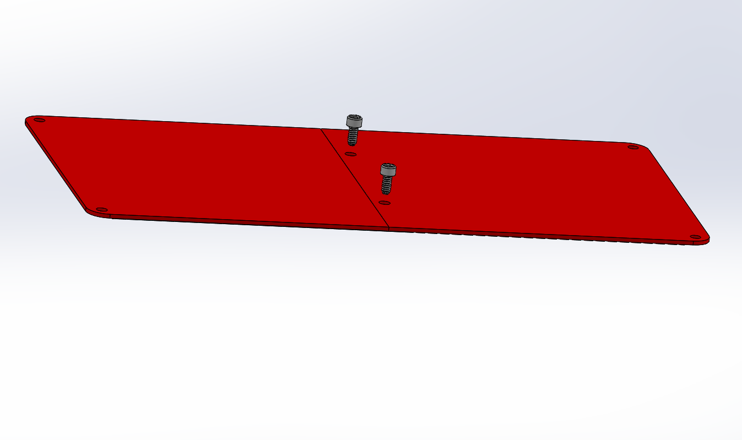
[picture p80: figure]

Figure 5: Back Plane connecting

5. Attaching the Back plane: Attach the back plane to the rest of the head structure

using screws B8.

Open Source Rover Mechanical Assembly Manual | Page 7

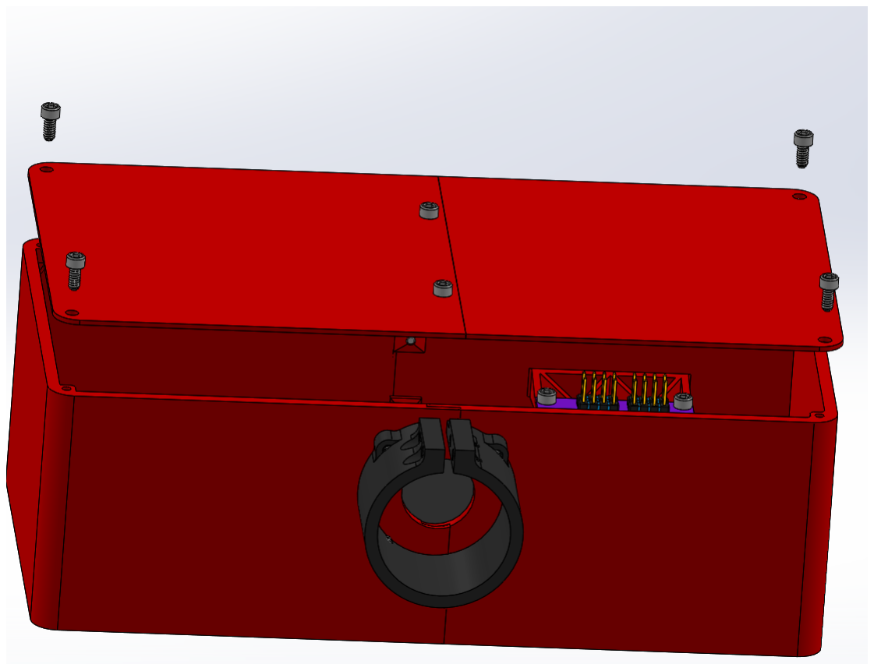
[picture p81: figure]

Figure 6: Attaching the Back plane

6. Attach the PVC pipe: Slide the length of PVC pipe you want for the neck into the

PVC clamping hub and tighten the screws the secure it.

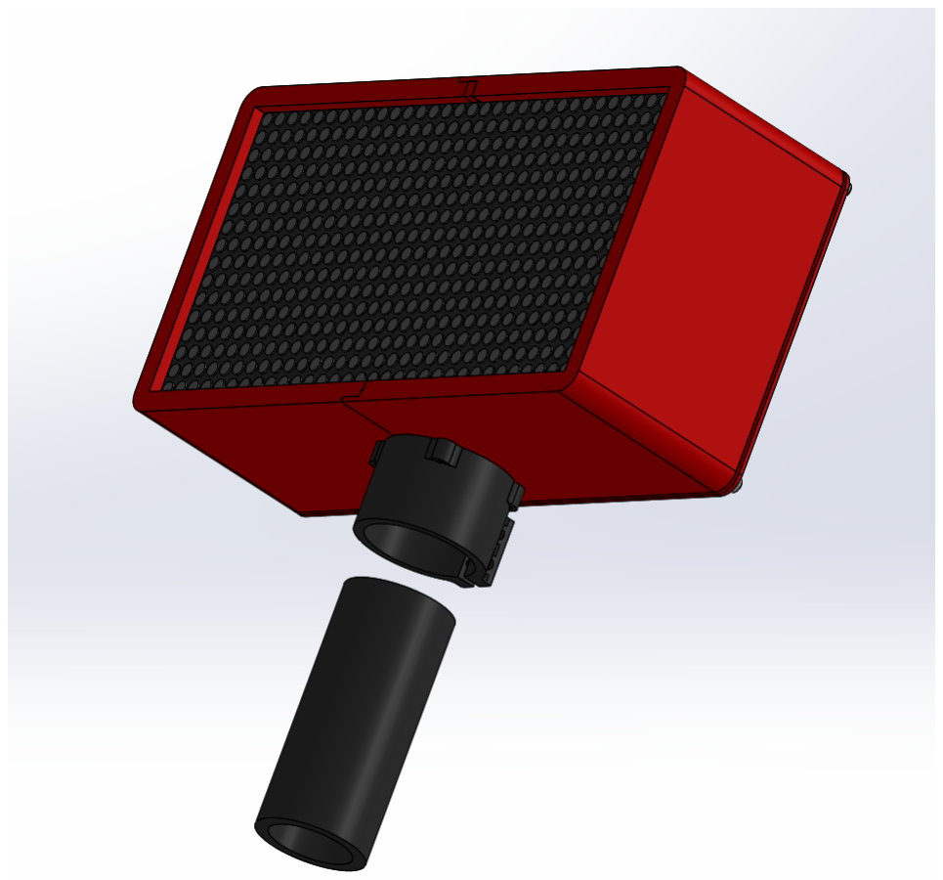
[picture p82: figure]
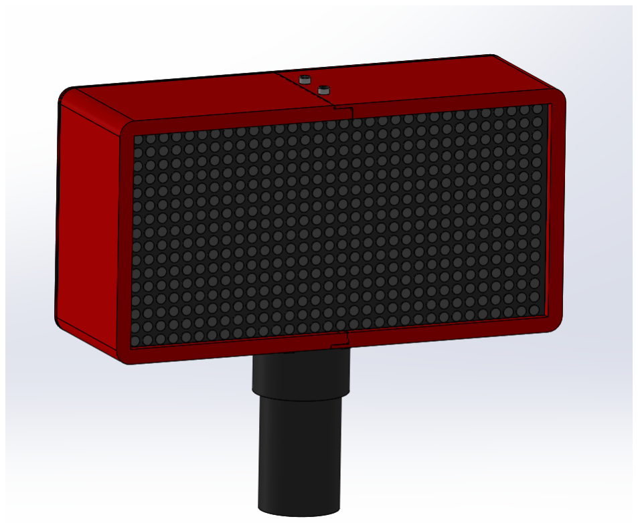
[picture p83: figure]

Figure 7: Attaching the PVC pipe

Open Source Rover Mechanical Assembly Manual | Page 8

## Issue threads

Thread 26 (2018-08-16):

Drive Motor Clamp - Mechanical over-constraint

ericjunkins, 2018-08-16:
## Problem
The attachment scheme for the drive motors leads to a mechanical over-constraint.

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

Here we can see that the clamping force on the aluminum 25mm Diameter motor clamp will be over-constrained when bolting the clamp into the aluminum U-channel

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

The red arrows show the force put on the piece from the clamping screw, and green arrows show force put on by bolting to the u-channel. These force are in direct opposition, and overtime lead to one of two things:

 * The motor loosens inside the clamp and is allowed to free spin, which will tangle and eventually break your wires
 * The clamp loosens inside the u-channel and the wheel assembly becomes loose to the rest of the robot chassis

## Solution
The motor should mount on using the bolting pattern at the bottom of the motor, similar to the corner motor mounting scheme. This will alleviate this over constraint and allow all pieces to be tightened properly

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

siero89, 2018-09-20:
what about if instead using a clamping screw u use a magnetic clamp ?

MisterUniverse, 2018-10-19:
Using a cotter pin at the end of the bolt will keep it from coming loose

ericjunkins, 2020-06-25:
Will be updating documentation for the screw tightening order to properly take up mechanical tolerances

Closed 2023-09-25.

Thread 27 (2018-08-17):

Clamping Hub: Mechanical over-constraint

ericjunkins, 2018-08-17:
## Problem

There is a mechanical over-constraint imposed by the 0.25 inch clamping hub used to attach the corner wheel assemblies to the corner steering assemblies.

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

This over-constraint is caused by the opposition of the clamping action of the clamping hub around the 1/4 inch shaft, and the bolting force attaching it to the aluminum U-channel

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

The force caused by the clamping hub is shown in red, and force from the bolting to the U-channel is shown in green. There is not enough tolerance in the clamping hub to both very tightly grip around shaft and bolt to the u-channel.

## Solution

In order to solve this issue you need to find a way to de-couple the attachment of the hub from the clamping force on the 0.25 in shaft. This could be done in many different ways, a few potential solutions would be:

 * Find a way to split this piece up into multiple pieces that are not coupled rigidly in those directions
 * Find a way to increase the mechanical tolerance in the bolting so that these forces are not in opposition

JHPHELAN, 2018-09-18:
What if you just left off one of the "front" vertical screws on the clamp out?  The clamp would remain held by 3 screws while allowing the horizontal tightening screw to pull the free half closer.  I'm no engineer so tell me if this is wrong-headed!
Jim Phelan, Mars Rover project lead, **Houston Robotics**

ericjunkins, 2020-06-25:
Will be updating documentation for the screw tightening order to properly take up mechanical tolerances

Closed 2023-09-25.

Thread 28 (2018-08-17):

Shaft Coupler -

ericjunkins, 2018-08-17:
## Problem

There is sometimes slippage in the attachment between the shaft coupler and the motor shaft

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

(this image shows socket head cap screws, which have been switched to button head screws for more clearance)

Even with the de-coupling of the two clamping forces across the coupler it still sometimes does not grab onto the motor shaft well enough to hold the entire torque seen on the corners.

## Solution

In order to keep the JPL open source rover up and running I've simply epoxied the couplers to the motor shafts, however for a hobby level project where one might want to change or reuse the motors this wouldn't be ideal.

Instead a coupler that can appropriately grab onto the 4mm motor shaft would be idea. This could potentially include a redesign of the scheme of attaching the motor so that you can get increased length of motor shaft to attach to as well.

davidadkins1, 2018-08-24:
Has anyone considered this? https://www.amazon.com/Stainless-Steel-Screw-Shaft-Coupler/dp/B00KQRRVHM

vssystemluba, 2018-08-24:
@davidadkins1 we used shaft couplers that were extremely similar to those ones in our first design of the rover.  We found that no matter how hard we torqued down those set screws, they would always back themselves out and lose grip on the shafts.

ericjunkins, 2018-08-24:
Initially we were using almost the exact part, however the torque seen on the corner system was higher than what the set screw was able to hold, and inevitably the set screws would loosen and back themselves out. Even with loctite this was the case eventually

vssystemluba, 2018-08-24:
On a semi-related note, I know some roboticists use motors hex drive shafts.  Without doing much digging, I found these... http://www.revrobotics.com/rev-41-1301/.  If we found a way to mount a motor with a hex drive shaft, we might be able to solve the shaft coupler problem.

ericjunkins, 2018-09-18:
I'm working on a potential 3D printed solution to this. I have designed and done a very quick test using an ABS based material, with good initial results.

**Proposed Solution**
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

**Motor Mounting Hub:**
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

Mounts the motor slightly higher up, but gives a more convenient access to the two screws that bolt into the motor. Instead of having to disassemble the entire coupler-standoff system to get to them the whole motor mount just uses the 4 bolting holes used for the pillow bearing standoffs as well.

**Shaft Coupler:**
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

This coupler takes advantage of the D-profile on both of the shafts, which will be the mating face for torque transmission. In addition with the decrease in outside diameter the upper half of the coupler can be extended to the entire length of the 4mm motor shaft, giving increased contact area. Set screws with heat set inserts will be added to handle axial loads only.

I'm going to test with ABS first and then afterwards test with Poly-Carbonate ABS well for increased hardness on the coupler.

vssystemluba, 2019-06-13:
Based on this discussion, the discussion and eventual solution on the OSR forum at https://www.tapatalk.com/groups/jpl_opensource_rover/shaft-coupler-solutions-discussion-t69.html, and @kevincloutier's pushed solution (9b407a6), I am closing this issue as solved.  Thanks everyone for the input and the design improvement!

Closed 2019-06-13.

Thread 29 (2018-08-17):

Corner Encoder System - General Improvement possible

ericjunkins, 2018-08-17:
## Problem

The absolute encoders used on the corner system are relatively expensive, and also require a voltage scaling solution to convert from the 0-5V analog output signal to the 0-2V scale that the RoboClaw motor controller accepts as input.

## Solutions

There are many potential solutions to this problem, and could be an improvement in complexity, or cost. Below are a few proposed potential solutions that could be explored further.

### Cheaper Absolute Encoders

One solution would be just using a cheaper absolute encoder, one example would be https://www.usdigital.com/products/encoders/absolute/rotary/kit/MAE3 . These would require a little bit of design work as they are to be mounted in-line with the output shaft of the motor. These are about $10 cheaper per encoder, but also allow you to skip buying the gearing system for each corner as well, meaning you save closer to $20 per corner

### Potentiometer

To greatly increase the cost savings on the system you could use a potentiometer (variable resistor) in order to do get the absolute position on the corners. This would be a bit more work on the design side to mount a pot in a correct way, as well as tune all the numbers correctly.  Below is a forum thread on arduinos' site that talks about this a little bit.

https://forum.arduino.cc/index.php?topic=262286.0

### Quadrature Encoder

Another high cost-savings solution would be to replace the entire absolute encoder system with a standard quadrature encoder (like the drive motors have on them already). This would save about $60 per corner for a total of ~ $240. However this system now loses all knowledge of absolute position every time it boots up. In order to make this implementation work a software calibration process would have to be written to find the position of the corners each time upon boot-up of the robot.

vssystemluba, 2019-02-07:
I'd like to throw into the discussion that another alternative is to use servos rather than dc motors for the corner steering.  There's some ongoing discussion about this already, but I figured it'd be valuable to mention that option here as well.

Playville, 2019-02-07:
Absolutely like that idea. I’m also experimenting currently with servos and noticed a better torque and more accuracy. Also it could save some money if you get rid of encoders.

vssystemluba, 2019-02-07:
@Playville that's fantastic.  If you wind up creating a solution that you're happy with, we'd love to take a look at incorporating it into the master instructions!!

Playville, 2019-02-07:
Sure thing! I’m about building it in 3D for some printing parts, I’ll keep you updated for sure!

lukeweston, 2019-08-01:
I'd consider using something like an AS5040 (DigiKey SKU: AS5040-EK-AB-ND for an assembled breakout board with the AS5040 IC.)

Requires a small diametric*  neodymium magnet, mounted to the end of the rotating shaft at the back of the motor etc, with the sensor IC mounted concentrically a couple of mm away from the magnet. Imagine a magnetic compass needle, which is the sensor, sensing the position of a rotating magnet hidden below it.

(* The magnetisation is 'across' the disk, not 'through' the disk as magnets usually are.)

This provides a non-volatile absolute index position (the north-south axis of the magnet glued to the shaft), high-resolution encoding, and standard quadrature TTL output, at a cost of about USD$10-20 per encoder (depending on economy of scale and whether you make the breakout PCB yourself.)

ericjunkins, 2019-08-01:
At a quick glance these use SSI as a communication protocol if I read correctly. What were you thinking about how to get them to communicate to the rpi

ericjunkins, 2019-08-01:
Also if you get the motor without encoders on them from either servo city or pololu neither of them expose the motor shaft out the back of the motor, only option is in line with the motor output shaft

dcschooley, 2020-01-01:
The RoboClaws have homing capability, where the motors are driven to a home position and the encoder position is set to zero when a switch is closed. It looks like it would work, but you need access to pins 24 and 25 (S4 and S5) on the controllers, and those pins aren't accessible in the Rev E. PCB design. If this works, you could get rid of the all of the absolute encoder stuff by adding a few wires, a switch, and maybe a resistor. There would need to be some software changes. The steering motors would be identical to the drive motors with the built-in encoders.

As a benefit, the rover would get to do a brief dance at every startup to do its own calibration of the encoder position.

Closed 2023-09-25.

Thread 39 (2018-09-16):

B10 screw incorrect

JHPHELAN, 2018-09-16:
The Master Parts List lists B10 as a M2.5 x 4mm cap head screw.
The Electronics Board parts list shows 11mm.
For consistency (gasp!) it should be a button head screw to match the others on the board.
McMaster only has even sizes in M2.5 button head hex screws, so 10mm:
https://www.mcmaster.com/92095a460

JHPHELAN, 2018-09-17:
On further exploration, the T7 M2.5 standoff is listed as 11mm long in the build but 12mm long on the Master Parts List and in the McMaster link.  Longer is better.  But the B10 M2.5 screw is listed as 11mm on the built but links to 4mm on the Master Parts List & Link, above.  The standoff is 12mm and had to accommodate a screw from both ends, leaving 6mm for each screw plus the thickness of the board on either end, 3mm for the Electronics Board and 2mm for the Raspberry Pi.  So the screws should be no longer than 8mm.  I bought some m2.5 x 8mm screws at Ace Hardware & they work OK.  M2.5 x 6mm hex cap head to match the others would probably be better: https://www.mcmaster.com/92095a458

ericjunkins, 2018-09-27:
This issue will be resolved during the merge of pull request #16

vssystemluba, 2019-03-12:
Resolved by e243445

Closed 2019-03-12.

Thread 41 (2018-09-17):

Electronics Board holes for Serial Splitter too small; holes for 5V regulator misaligned.

JHPHELAN, 2018-09-17:
1) On the laser cut Electronics Board, in the lower right corner, the holes for the Serial Splitter PCB are too small.  They should accommodate the #4-40 screws needed for the #4-40 spacer, but they won't fit.
2) In the same corner, the holes for the 5V regulator should be **21mm** or 13//16" apart (instead of 20mm).  Also, according to both the diagram and the photo, the holes should be oriented on the opposite diagonal (NW-SE instead of NE-SW).  Won't know until we get to wiring whether that's important.

ericjunkins, 2018-09-18:
I do believe that might be correct about the 5V reg being flipped upside down. I will update the drawing to have the appropriate dimensions and be oriented correctly, sorry about that mistake.

As far as moving forward for you, I think there are a couple of options.

1. Match Drill the hole pattern in the acrylic yourself. A 2-56 screw is relatively small and you would run little risk of cracking acrylic if you choose to do this and are careful.

2. Install the header pins upside down on the 5V regulator and then make sure to connect things accordingly.

3. Make your own layout and design for the electronics board assembly and let us know!

jaeme, 2018-09-18:
HI I can't seem to download the dxf files.
Can you please help.
Thanks

ericjunkins, 2018-09-18:
@jaeme What do you seem to be having trouble with? Do you have the repository cloned locally on your computer?

jaeme, 2018-09-29:
@ericjunkins when I go to the DXF file it comes up with the GCode - code.
What is the repository cloned please.
Thanks

ericjunkins, 2018-09-29:
@jaeme This link is for githubs documentation on how cloning the repository

https://help.github.com/articles/cloning-a-repository/

Do this on the main github repo at:

https://github.com/nasa-jpl/open-source-rover

The dxf files should be there for you to access

jaeme, 2018-09-29:
@ejunkins thank you for your help and apologies about being such a novice

Closed 2018-09-18.

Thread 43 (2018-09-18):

Electronics Board: shortest RoboClaw needs 8 x #4 washers to make tight

JHPHELAN, 2018-09-18:
The 5th RoboClaw motor controller on the Electronic board is supported by #4-40 1/4" stand-offs and 4-40 1/4" screws.  1/4" stand-off shared by 2 screws = 1/8" each.  The Electronics Board is 1/8" acrylic allowing its screw to extend 1/8".  The RoboClaw board is only 1/16" leaving a gap of 1/16" play when its screw meets its partner in the stand-off.  A couple #4 washers does the trick and there's plenty left over.  The purpose of the staggered elevation of the stand-offs is supposedly to allow room to access the USB port on the RoboClaw for testing and calibration.  Seems this could have been accomplished as easily by rotation or translation of the RoboClaw but we won't know til wiring time what the reality of that situation is.
Jim Phelan, Mars Rover project lead, **Houston Robotics**

ericjunkins, 2018-09-18:
I"ll look into these comments on screw lengths and standoff lengths. It is true rotation could have been done to have access to micro USB ports, I chose to keep the wire routing for the Power to the motor controllers as simple as possible. I certainly would be open to suggestions as to other possible configurations of electronics boards that could make things easier! :)

vssystemluba, 2018-12-06:
Closing this issue as there are workarounds mentioned above.  @JHPHELAN if you feel strongly that this should be referenced in the master build documents, please submit a pull request and we'll get it merged.

Closed 2018-12-06.

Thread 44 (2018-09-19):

Can not access Mechanical/Mechanical Integration/Rover 3D view.pdf

CWRatliff, 2018-09-19:
All other 3d .pdf's are fine, but "Rover 3D view" shows only a small colored axis system at bottom left of page.

ericjunkins, 2018-09-20:
I tried a few times to generate the 3D pdf of the rover model, every time resulting in SolidWorks crashing. It might end up being too big to successfully  generate the 3D pdf from

ericjunkins, 2018-09-20:
I'm going to explore if there are other options to give a 3D model of the rover for someone to view who doesn't have access to any CAD software, but for now I'm going to remove the Rover 3D view pdf as it is blank.

CWRatliff, 2018-09-20:
Hi Eric,

Thanks for addressing the Rover 3D issue. I hoped to use it to resolve a potential engineering problem.

As I understand it, the middle wheel's motor mounting channel attaches to a 1.5" channel using two channel connectors. That's OK, but then the 1.5" channel attaches to the bogie using only one channel connector. This looks like an eventual metal fatigue problem.

I was unable to find a ServoCity part that looked like it would work.

I machined a .25 thick aluminum part that is nearly identical to the channel connector part in the flat view but has two tapped holes on the ends to allow connection between the 1.5" channel and the 3.75" bogie part.

I'm very willing to share this part design if anyone is interested.

Thanks, Wayne

-----Original Message-----
From: ericjunkins <notifications@github.com>
To: nasa-jpl/open-source-rover <open-source-rover@noreply.github.com>
Cc: CWRatliff <CWRatliff@aol.com>; Author <author@noreply.github.com>
Sent: Thu, Sep 20, 2018 9:14 am
Subject: Re: [nasa-jpl/open-source-rover] Can not access Mechanical/Mechanical Integration/Rover 3D view.pdf (#44)

Closed #44.
—
You are receiving this because you authored the thread.
Reply to this email directly, view it on GitHub, or mute the thread.

ericjunkins, 2018-09-20:
@CWRatliff Yeah I had looked for a while to find a part that interfaced correctly from ServoCity.

You are correct about the middle wheel assembly attaching to the bottom of the rocker-bogie on only the one side. The channel connectors are steel however, and I don't think that metal fatigue would be your biggest downfall to this design, as the weight and stress that part sees are relatively low compared to the strength of steel.

What I do see happen is over time on a lot of the screws that go into the channel connectors that eventually they back themselves out from vibrations over time (even with loctite and lock washers it eventually happens). Now our rover sees a lot of moving, we take it to events all around, so has lots of car rides and transportation. This issue of screws backing out is worsened by the fact that there are only two screws on each piece and they are planar, not opposing, so as soon as one starts slipping out the other one will much faster as well.

I'd love to see the part you designed for this, and as I said it takes very little load overall, it likely is a component that could be 3D printed if access to a machine shop/equipment isn't viable.

CWRatliff, 2018-09-21:
Hi Eric,

Attached is a picture and hand sketch of the part I described. Hope this is useful.

Wayne

-----Original Message-----
From: ericjunkins <notifications@github.com>
To: nasa-jpl/open-source-rover <open-source-rover@noreply.github.com>
Cc: CWRatliff <CWRatliff@aol.com>; Mention <mention@noreply.github.com>
Sent: Thu, Sep 20, 2018 1:54 pm
Subject: Re: [nasa-jpl/open-source-rover] Can not access Mechanical/Mechanical Integration/Rover 3D view.pdf (#44)

@CWRatliff Yeah I had looked for a while to find a part that interfaced correctly from ServoCity.
You are correct about the middle wheel assembly attaching to the bottom of the rocker-bogie on only the one side. The channel connectors are steel however, and I don't think that metal fatigue would be your biggest downfall to this design, as the weight and stress that part sees are relatively low compared to the strength of steel.
What I do see happen is over time on a lot of the screws that go into the channel connectors that eventually they back themselves out from vibrations over time (even with loctite and lock washers it eventually happens). Now our rover sees a lot of moving, we take it to events all around, so has lots of car rides and transportation. This issue of screws backing out is worsened by the fact that there are only two screws on each piece and they are planar, not opposing, so as soon as one starts slipping out the other one will much faster as well.
I'd love to see the part you designed for this, and as I said it takes very little load overall, it likely is a component that could be 3D printed if access to a machine shop/equipment isn't viable.
—
You are receiving this because you were mentioned.
Reply to this email directly, view it on GitHub, or mute the thread.

ericjunkins, 2018-09-21:
@CWRatliff It looks like you replied to that via email, which it doesn't upload attachments from

CWRatliff, 2018-09-21:
[channel connector.pdf](https://github.com/nasa-jpl/open-source-rover/files/2406486/channel.connector.pdf)
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

CWRatliff, 2018-09-21:
[channel connector.pdf](https://github.com/nasa-jpl/open-source-rover/files/2406489/channel.connector.pdf)

Closed 2018-09-20.

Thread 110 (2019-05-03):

Decoupling capacitors on opamps

lukeweston, 2019-05-03:
A decoupling capacitor (say 100nF) should be provided at the Vcc pin on each of the voltage-follower opamps in the encoder system. Given the use of long wires and amateur construction with DuPont jumper wires, parasitic inductance in the 5V supply wires is likely to be significant, and the proper use of decoupling capacitors at each IC is universally good practice.

The master BOM says that 4x LM358 are used - but is this correct?
There are 4 encoder channels, so 2 LM358s should be needed. (They are a dual opamp.)
In fact, a single quad opamp could be used (eg. LM324) meaning one less part.

15kΩ : 10kΩ would provide the most correct voltage division of 5V to 2V, assuming zero output impedance in the encoder, and remains a common E12 value.

Wouldn't choosing an encoder with TTL quadrature output and connecting this to the motor drive board completely eliminate the need for this circuit, instead of purchasing encoders with the analog output option?

ericjunkins, 2019-05-03:
@lukeweston Have you looked at the electronics-pcb-rework branch? https://github.com/nasa-jpl/open-source-rover/tree/electronics-pcb-rework . This has implemented decoupling capacitors on the encoder lines. There are only 2 LM358 used correct, that is a typo in the BOM.

As far as the voltage division I felt it was better to over divide the signal and take it to a 0-1.6V range and sacrifice a tiny bit of resolution to avoid any clipping issues. The angular resolution becomes 1 deg ~= 4.444 encoder ticks, which with filtering caps noise fluctuations are then on the +/- 0.5 deg, which we found more than acceptable for the project.

Having an absolute quadrature encoder would solve that yes, if you have any part suggestions feel free to make some suggestions. We thought that there is some benefit as a teaching project to not just have every item be plug-and-play, and provide some change to build some circuits and test/learn that as well.

Thanks for the questions!

Closed 2019-05-04.

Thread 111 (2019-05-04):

Aluminium and PVC tube stock

lukeweston, 2019-05-04:
Just a quick question:

The 5 feet of specified PVC tube appears to be only used to cut a single 6” length to mount the “head” assembly, and nothing else?. Is that correct? (I recognise that the mast may be a little taller, for sensor or camera use, but it seems like a foot or two of stock material will be more than adequate. Since McMaster-Carr is inaccessible to non-USA customers, I need to make some adjustments to the BOM.

Similarly, the 12.7mm aluminium tube used in the differential pivot assembly is cut into a 13.5” piece and a 15” piece, but there appears to be only one piece used? Where does the 15” piece get used, I can’t find it? I will source this material in a single piece without buying 3 feet of it.

Similarly, the 1/2” tube in the differential pivot assembly appears to be clamped on the outside and therefore its ID (and hence wall thickness) is not critical and may be changed. Is this correct?

ericjunkins, 2019-05-04:
You do only need the 6inch segement for the head assembly for PVC.

The 0.5 inch (12.7mm) aluminum tubing is used in the differential pivot for the 13.5 inch piece, and the 15 inch piece is used in the mechanical integration step. We are looking into solutions that wouldn't require buying these as one piece, and instead getting two pieces of exact length ordered.

Wall thickness does not matter, as long as it is still sufficiently thick to resist bending.

ericjunkins, 2019-05-04:
@lukeweston Do you know about the forum we have?

https://www.tapatalk.com/groups/jpl_opensource_rover/

This is a more appropriate place to ask questions, as these are not really issues that need fixing. General questions and discussions are better suited for the forum

Closed 2019-05-04.

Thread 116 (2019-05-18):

Monolithic board Electrical Assembly Instructions errors

JHPHELAN, 2019-05-18:
Electrical Assembly Instructions OMITTED D1 and F1.
They're clearly installed in the photos, but no reference in the instructions.
They're the last left-over parts and slots prior to placing the standoffs.

On the PCB J13 (GND +12V) is omitted from the instructions.
On the BOM, J13 is the 5.08mm 2P side entry terminal block.
But that is too large for the holes which match the 3.5mm J6 for the Arduino shield
(not to be confused, but it is, with the J6-7 2x20 40P ribbon cable connectors.)
There are 3 slots on the PCB for the 5.08mm 2P connectors labeled J15 (BATTERY IN), J16 (POWER SWITCH) & again J16 (BATTERY OUT).
Not sure what this J13 is supposed to do, but one of the two 3.5cc 2P terminal blocks is going into it.

Jim Phelan
Mars rover project lead
USAi Labs (formerly Houston Robotics)

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

ericjunkins, 2019-06-10:
@JHPHELAN Sorry I Must have missed this issue. Solving this currently by adding the instructions for which piece goes here. It is just a breakout of the 12V regulator line. I'm sure you had figured that out by now.

ericjunkins, 2019-06-10:
Fixed in commit 4b494c4

Closed 2019-06-10.

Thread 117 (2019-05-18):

Optional CAD parts heat-set-inserts #4-40 not #6-32?

JHPHELAN, 2019-05-18:
The Optional CAD parts lists a number 6 heat-set-insert for the new Arduino and back plate head mounts.  I bought both 6-32 and 4-40 for future use.  With some trepidation I tried the new technology on an old scrap rover back plate.  The holes were just the size of the 4-40 insert and too tight for the 6-32.  I drilled open one hole a couple sizes to just fit the narrow end of the 6-32.  Applying a needle tip soldering iron they both eased into place.  The 4-40 insert slipped out when pulled by a screw as the hole was a bit too large.  The 6-32 held nicely.  On the Arduino head, the 3D printed holes appear to better fit a 4-40 insert than the 6-32.  I'll wait for clarification on this before applying the soldering iron!

Jim Phelan
Mars rover project lead
USAi Labs (formerly Houston Robotics)

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

ericjunkins, 2019-05-18:
The head-base CAD part calls for M2.5 inserts actually. I can eventually change these to be 6-32 or 4-40 inserts to be consistent with some of the other things bought. I generally am using metric stuff at work at so my stockpiles are generally better for metric. The arduino plate would also be made for M2.5 screws/inserts, though I believe you could get away with 4-40s in them, they should be pretty close. In general the insert will not just push into the material, it should be melting away a bit of the walls as you push it in such that it actually is inset into the plastic. Because of this M2.5 and 4-40 are pretty similar, and M3 and 6-32 are also pretty close when it comes to the inserts.

ericjunkins, 2019-07-26:
Fixed in 71b9e5356ee9e42fb068ee36b2e46d12b22ea870

Closed 2019-07-26.

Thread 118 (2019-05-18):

Monolithic board testing fails at step two!  Test pad T2 isn't GND

JHPHELAN, 2019-05-18:
**Electrical Assembly Instructions / 2 Component Integration and Testing /
2.1 Power Distribution System:**

"1. Begin by powering the board. In order to do this we will be bypassing the switch and
volt meter, so this connection will look a little bit different than when you fully install
the board into the rover. Insert the red wire on the Tamiya Battery Connector E35
into the IN terminal on connector J16, and the black wire to the GND terminal on
the connector J15."

Do we _really_ want to connect the battery to two different terminal blocks, or is one of these a typo?  [apparently it DOES work once you realize that T2 is NOT ground but use the battery ground as reference]

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

"2. Using a Digital Multimeter (DMM) probe the voltage accross the test points T1 and
T2. These will tell you the voltage level that the board is at, which is the direct voltage
of the battery. Verify that from T1 to T2 reads a positive number, and is between 12V
and 16.7V depending on the charge state of your battery."

Doing this, there is NO voltage between T1 and T2 when voltage is present between the two wires.

Connecting the battery to the more logical terminals on J15 has a similar problem.  Even shorting the POWR SWITCH J16 terminals failed to produce a voltage.

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

Further continuity testing revealed that test pad **T2 DOES NOT CONNECT TO GROUND**.  All the other GND terminals on the board DO test as connecting to the GND terminal of BATTERY IN.  I got an error message trying to view the PCB in KiCAD so I can't trace the problem.  I'll have to skip this part and proceed under the assumption that T2 is mislabeled or not connected.  So far no mention in the directions about installing the 12V or 5V regulators so they are not installed at this point.

"INSERT IMAGE OF ROBOCLAW WITH WIRES IN IT AND ROBOCLAW CON-
NECTION TO BOARD"  Permission granted.

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

Jim Phelan
Mars rover project lead
USAi Labs (formerly Houston Robotics)

ericjunkins, 2019-05-18:
I guess when I say "GND" yes this is being loose with the term "Ground". It refers to Battery Ground, or the (-) terminal of the battery. This is not Earth Ground.

Below shows the schematic of the board.
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

I will have to dig in further to that test point, i'll try and verify with my boards.  What is the error message from KiCAD? I want to make sure people can view/edit these boards so I want to try and help fix that as well.

JHPHELAN, 2019-05-19:
@ericjunkins
I assumed that GND meant board GND / battery GND.  But T2 doesn't have continuity to  battery GND unlike every other GND designated terminal on the board.  However, if you ignore the problem with T2 and measure against any actual GND on the board, it measures ok so far as I've gotten.

The obviously old (as it bears little resemblance to yours) schematic I have (Monolithic Board.pdf) shows:
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

But I was less concerned about the labels as the actual board traces.  I may well be misusing KiCAD as I am not at all familiar with it, but when I tried to look at the actual construction of the PCB (Monolithic Board.pro) in KiCAD I got:
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

Jim Phelan
Mars rover project lead
USAi Labs (formerly Houston Robotics)

JHPHELAN, 2019-05-19:
BTW, my teacher at TXRX makerspace for Python & OpenCV, Dan Mailman, taught us that documentation always takes a back seat to creation.  EXPECT that documentation will be incomplete, out of date and inaccurate.  Just be pleasantly surprised when it actually works as hoped, just like your program.  That attitude has saved me a LOT of frustration!
JHP

ericjunkins, 2019-06-10:
@JHPHELAN I'm trying to close some of these open issues one by one here. I should expect that T2 is always GND for the system no matter what. Were you still seeing issues where it was not? I wouldn't expect that to happen and am just trying to check and see if this still needs to be an open issue or not.

JHPHELAN, 2019-06-10:
On my board T2 did not connect to anything.  Continuity check between it and  any other GND tests OPEN.
JHP

ericjunkins, 2019-06-10:
Ah okay, I found the error.. the following test point is not actually connected into the net.
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

leading to this via/net not being connected into the GND plane.
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

Fixed here:

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

Closed 2019-06-10.

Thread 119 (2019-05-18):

M2A & M2B on the PCB are reversed vs the RoboClaw

JHPHELAN, 2019-05-18:
On the monolithic controller PCB, the labels for the terminal strips that jumper to the RoboClaw at M2A and M2B are **reversed**.  M2A is to the outside of the RoboClaw whereas the terminal strip outside connector is labeled M2B.  I hope it's just the labels that are backwards and not the internal wiring.  Else the wires between each RoboClaw and the PCB for M2 with have to be switched at one end.

Jim Phelan
Mars rover project lead
USAi Labs (formerly Houston Robotics)

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

ericjunkins, 2019-05-18:
The motor terminals do not particularly make a difference which is which for A and B, you can reverse the polarity during calibration such that it applies voltage to make it correct for "forward" of the rover

JHPHELAN, 2019-05-18:
All 5 RoboClaws power up!
JHP

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

ericjunkins, 2019-05-18:
Looks great! I do appreciate the feedback and pictures with your process putting this together. I know we released it at a very prototype-level stage and appreciate those of you who are helping test documents etc.

JHPHELAN, 2019-05-19:
2.4:
"INSERT IMAGE OF ROBOCLAW WITH WIRES IN IT AND ROBOCLAW
CONNECTION TO BOARD"

Permission granted.
Jim Phelan
Mars rover project lead
USAi Labs (formerly Houston Robotics)

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

vssystemluba, 2019-06-13:
Thanks for pointing this out.  Even though it will be calibrated either way, I went ahead and flipped the silk screen labels (d2542d7) to keep others from getting confused.

Closed 2019-06-13.

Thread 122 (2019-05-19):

Arduino Sheild Silkscreen backwards on Connector J1

JHPHELAN, 2019-05-19:
@vssystemluba @ericjunkins

Could y'all please post a pic of the assembled Arduino shield?  Most of it seems obvious but I need to clarify before applying solder.  I'll trade you a step-by-step album!  Thanks!

Jim Phelan
Mars rover project lead
USAi Labs (formerly Houston Robotics)

ericjunkins, 2019-05-20:
Will do when I get a moment thanks.

JHPHELAN, 2019-05-21:
I _believe_ it should look like THIS except I'm unsure about the orientation of the 3 connectors.
The power connector is too dark in this web view but is facing the far edge of the board
(you can save it and open it on your own computer to see it properly) :

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

Jim Phelan
Mars rover project lead
USAi Labs (formerly Houston Robotics)

ericjunkins, 2019-05-21:
As long as that 6 pin JST connector matches with the cable orientation you installed in your control board it is fine. See below pictures of where the 12V line is in both of them.

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

It also occured to me that the silkscreen is backwards on the J1 connector on the arduino shield. That was initially in a different location and upon moving it the silkscreen didn't get updated correctly. So that is mirror flipped as you can see below

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

JHPHELAN, 2019-05-22:
@ericjunkins Based on your circuits above, I assembled the Arduino shield as below.
The only difference to my sample above is reversing the JST connector to face outward.
Looks like we need a Rev 2 of the PCBs with the silkscreen reversals corrected & showing the key notches on the silkscreens to avoid confusion.  If there was a way to indicate on the PCB which way the header pins go, that would help too.

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

Jim Phelan
Mars rover project lead
USAi Labs (formerly Houston Robotics)

vssystemluba, 2019-06-13:
@JHPHELAN thanks for helping to add clarity here.  I've pushed a change to the silk screen (d2a88c6) that flips the labels which hopefully make things a little clearer.

Closed 2019-06-13.

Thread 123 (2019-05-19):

Control Board Silkscreen Backwards for Motor Connector Terminal Blocks (left/right flipped)

JHPHELAN, 2019-05-19:
The revised Body Build Doc.pdf shows the monolithic control board hanging from the top of the rover with the R Pi hang down.  The BATTERY IN is near the Differential Pivot Block.  (An issue is noted with conflict with the neck's PVC mounting hub but I solved that just my moving the neck mount one hole closer to the center.)  In this position with the Differential Pivot Block at the rear and the neck at the front, the motor terminal blocks are on the OPPOSITE side of the rover from their labeled motors.
Now what?
a) ignore the R/L reversal as a silkscreen typo, everything is actually fine inside the PCB & software.
b) ignore the R/L labels, wire the motors to the appropriate terminal block on the same side as the motors and handle the reversal in an upcoming software release or, please no,
c) criss-cross the wires to the opposite side of the board.
Waiting to tune the RoboClaws until this is clarified.

Also noted the U channels that used to support the old Electronics Board have been replaced by Dual Side Mount A's.

Jim Phelan
Mars rover project lead
USAi Labs (formerly Houston Robotics)

ericjunkins, 2019-05-20:
The silk screens are not a type on that case, the traces are in fact what they are labeled. But you should do option B). Polarity of the motor will make no difference and you will have to go on a motor-by-motor basis and verify that 'forward' command for pwm is 'forward' for the robot anyway, so just choose the correct polarity then

JHPHELAN, 2019-05-20:
@ericjunkins   It's not just a matter of polarity of the motors.  The entire right side of the rover is wired to the left side of the board and vice versa.
JHP

ericjunkins, 2019-05-20:
Oh sorry I am mixing up what we were taking about... What do you mean it is left right flipped? That is a matter of what you're calling left /right from facing the rover or facing with the rover is it not? I did not criss cross the wires across the body, and my board is installed with the battery terminals near the differential pivot

JHPHELAN, 2019-05-20:
@ericjunkins
I mean from the point of view of the rover itself as it is moving forward.  The terminals (J20, J21, J22, J25, J26) that are labeled for the motors (motors 1,2,8,9,&10) on the RIGHT side of the rover are located on the LEFT side of the PCB as it is mounted in the rover, and vice versa.
JHP

ericjunkins, 2019-05-21:
The J20,21,22,25,26 connectors should go to the right side of the rover, from the rover's frame of reference. To be fully clear I have boxed the motors I would expect that to control below:

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

This appears on the left of the board, because the board is put into the robot upside-down, such that the Motor controllers which are on the "bottom" of the board will face upwards in the body, and the Raspberry Pi which are on the "top" of the board face downwards in the body. Does this answer the issue here?

JHPHELAN, 2019-05-21:
No, that is exactly the issue.  In that position it seems the terminals for those motors are on the opposite side of the rover.
JHP

ericjunkins, 2019-05-21:
Right, okay. I'm on board now. The silk Screen for left should say right and vice versa.

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

Here is the PCB layout of the board. You can trace roboclaw to motor terminal here, but it seems that the left/right is upside down on the silk screen only, and that the traces go to the correct terminals

JHPHELAN, 2019-05-21:
Phew!!  Now I can proceed toward installation!
Thanks!!!
JHP

vssystemluba, 2019-06-13:
Thanks @JHPHELAN for pointing this out.  I've swapped the silk screen labels so they are consistent with the actual traces (d2542d7), and hopefully we saved other groups some confusion in the future!

Closed 2019-06-13.

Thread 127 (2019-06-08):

3D printed battery holder doesn't fit battery

JHPHELAN, 2019-06-08:
Just printed the battery holder but find it doesn't fit.  Has anybody else tried this?  Made a fix?
JHP

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

ericjunkins, 2019-06-08:
oh, I forgot that I have a slightly higher capacity battery in mine so it is a bigger battery. Can you measure the dimensions of the battery and I can give you an updated part for it?

JHPHELAN, 2019-06-08:
@ericjunkins
[https://www.batteryspace.com/li-ion-battery-14-8v-5-2ah-77wh-8a-rate-for-diving-light---un-38-3-passed.aspx](url)
"Dimensions  1.6"(43mm) H x 1.6"(43mm) W x   5.5 "L(139mm)"
I measure from the 2 flat sides, avoiding the bumpy wire, side **1 15/32"** a little less than the specs.
If the top of the holder were lowered to an inside jaws clearance of 1 15/32" it would be good.

JHP

ericjunkins, 2019-06-08:
yeah the dimensions of the datasheet aren't usually quite correct for these, they tend to be a bit bumpy and differently shaped. I'll upload a fix of that part

JHPHELAN, 2019-06-09:
@ericjunkins BTW the bottom holes are too big for 4-40 and just a little small for the 6-32 heat set inserts.
The 6-32 would probably melt its was in but the narrow end wouldn't have a clean start.
JHP

ericjunkins, 2019-06-09:
I've had no issues putting #6-32 heat set inserts in these parts

ericjunkins, 2019-06-21:
@JHPHELAN I finally got around to making edits of this for the 5.2mAH battery size. Can you let me know if this fits well or if it needs tuning still? It can be found at https://github.com/nasa-jpl/open-source-rover/blob/electronics-pcb-rework/Optional%20CAD%20parts/STL/battery%20holder_5_2maH.STL

ericjunkins, 2019-06-24:
My part for the test fit of this can be seen below:

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

I believe this fixes this issue and will close it based on commit b441a83c82498513b61260dd79068bb3b2afc41f

Closed 2019-06-24.

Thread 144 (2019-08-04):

Add Kitspace compatible electronics BOMs?

kasbah, 2019-08-04:
Hey, I noticed in the readme it says:

> The Bill of Materials folder contains (currently just one) Bill of materials file for a specific vendor. We are searching for better ways to help with the ordering process

This is exactly what my open source project [kitspace.org](https://kitspace.org) is for! It lets you buy across the 5 currently supported distributors with a single click.

To mirror your PCB designs there we need to add a few files: a manifest and the electronics BOMs (can be csv, xlsx or ods) separated into PCB files. When you update the repo on GitHub in the future it will automatically sync your changes. We do have a BOM export script for KiCad as well.

I would be glad to work with you on this and put this project up. Are you interest?

vssystemluba, 2019-08-06:
@kasbah we're very interested in anything that helps folks get their parts easier, faster, or less expensively!!!

Would you be willing to take our BOM and build out a project on kitspace to show us what that would look like?  It'd be great to get an updated BOM with easier carts / ordering for folks.

Do note that we build our master parts list / BOM dynamically from our build instruction files.  There may need to be a little thought going forwards about maintaining accuracy and consistency, but even as a first pass having something like a kitspace project (even for a static BOM as it exists today) would definitely add value over what we already have available.

I'm going to close out this issue here since it's not an issue against our repository per se, but I'd love to see what you can come up with in kitspace for this project.  We can continue to chat on this issue or on the OSR forum (https://www.tapatalk.com/groups/jpl_opensource_rover/).

vssystemluba, 2019-08-06:
(And FYI if we get a kitspace project / BOM to an acceptable place, we will definitely link to it from our main repository!)

kasbah, 2019-08-07:
Awesome! @kevinb456, would you be up for generating the BOMs and sending the appropriate pull-requests or should I do it?

I think as a first step we'll add two .csv to the `Bill of Materials Files` folder one for `Arduino_uno_sheild` (sic) and one for `Control Board`. We should be able to use our [KiCad scripts](https://github.com/kitspace/1clickBOM/tree/master/output_scripts/kicad) and then reconcile that with your Digikey BOM. One issue is that you haven't been using the actual PCB schematic references in any BOMs? I am sure we can figure it out though.

Maybe we can set up a script for you to re-generate these in the future if any of the electronics design change and also incorporate that into your build.

Interested by your approach in general. In my other job we develop an open source microscope ([openflexure.org](https://openflexure.org)) and we are developing a tool called [git-building](https://gitlab.com/bath_open_instrumentation_group/git-building) to generate BOMs from markdown descriptions. It seems like a very similar approach except you are using `.tex`. I like that your "master parts list" is a spreadsheet (we have been using yaml for a similar purpose but I like this better).

Closed 2019-08-06.

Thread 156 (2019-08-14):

In the Head Build instructions, but is the shield attached in step 4.1 without soldering the connectors?

toebes, 2019-08-14:

mikcox, 2019-08-22:
All connections should be soldered previous to mounting the shield to the Arduino; the CAD just didn't originally include those pins and so they were omitted from the photos.  I've retaken photos from the OnShape model and updated the head assembly document accordingly to add some more clarity.

Closed 2019-08-22.

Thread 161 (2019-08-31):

Fasteners in Corner Steering Assembly: B5 too long, should be B3. B1 unused.

Roger-random, 2019-08-31:
**RE: Corner Steering Build Doc**

It called for 6-32 3/4" long screws (B5) for fastening corner steering motor mount (S9) through channel (S2) into standoff (T9).

It appears the threaded hole in standoff (T9) is not deep enough to accommodate that length screw. Some report success with 5/8" (B4) but the depth is not consistent. At least one build required going down to 1/2" (B3)

These fasteners (B5) are also used later in the document to fasten pillow bearing blocks (S10) and encoder mount (S31) to standoff (T9). This would consume the 16 (4 per corner) listed in the document.

Possibly related: the parts list (Table 1) in this document also calls for 6-32 1/4" screws (B1) but they do not appear to be used in the assembly.

**Suggestion:**
- In Table 1: replace B1 with B3, change quantity from 24 to 16
- In motor mount instructions: replace B5 with B3

Leave B5 reference and quantity unchanged in Table 1, they are used in pillow bearing block assembly.

Roger-random, 2019-08-31:
Related forum thread: https://www.tapatalk.com/groups/jpl_opensource_rover/screw-length-for-corner-steering-motor-block-throu-t92.html

darpatel, 2020-01-03:
The actually CAD calls for B1s that fixed it for us

Achllle, 2021-01-24:
This has been resolved!

Closed 2021-01-24.

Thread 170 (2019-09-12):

Electrical Build doc: Inconsistent wire gauge X1, X2. 16 or 20 AWG?

Roger-random, 2019-09-12:
In Electrical Build.pdf:

Table 1 parts to build battery connector lists X1 (red) and X2 (black) as 16 AWG wires.

Table 3 in the same document lists X1 and X2 as 20 AWG wires.

Parts list describe X1/X2 as 20 AWG wires and that's what I purchased.

If table 1 is incorrect and we're supposed to use 20 AWG wires for battery, the typical guidance for wires recommend not to exceed 5A for 20 AWG. 20 AWG wires may burn up before tripping the 10A fuse.

If table 1 is correct and Table 3+parts list is wrong, 16 AWG is awfully thick to route through rover suspension for motors.

Perhaps the wires of table 1 and 3 are intended to be different wires of different gauge?

Achllle, 2020-07-02:
The battery wires should definitely be at least 16AWG but I'd propose to even go to 12AWG which should be able to handle around 30A. When all motors are accelerating at the same time (corner + drive), we could easily hit such a value.
@ericjunkins does that sound reasonable to you? What kind of current can the PCB handle?

apollokit, 2021-04-20:
Update:

the table 1 referred to above is now table 3 in [this subsection](https://github.com/nasa-jpl/open-source-rover/blob/master/electrical/electrical_build.md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)

the table 3 referred to above is now table 6 in [this subsection](https://github.com/nasa-jpl/open-source-rover/blob/master/electrical/electrical_build.md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)

Agreed that the wires of table 3 and 6 are meant to be different. The X1 and X2 designators are incorrect in table 3.

Seems like, per @Achllle 's proposal, we should use 12 AWG for the battery connections, and update table 3 and the parts list accordingly.

@Achllle, @ericjunkins , sound good?

Achllle, 2021-04-20:
Sounds good to me; it's what I currently use and I don't find the wires to be too thick to work with. I'll let @dcschooley or @ericjunkins decide if that's too much.

dcschooley, 2021-04-20:
12AWG is only too much if is too big for the terminal blocks. That size is a waste of copper for those short connections however.

ericjunkins, 2021-04-22:
Has anyone tried to plug 12 AWG into the roboclaw terminal blocks? It sounds like thats the proposal? that seems hard to work with for those connections

Achllle, 2021-04-22:
Yes, I have. It works but it is on the bigger size. I think if 14 or 16 AWG is safe and can deliver the power we should use that.

ericjunkins, 2021-04-22:
I mean i use 20 AWG on mine so Anything is probably going to be fine. The wires are all such short distances it barely matters

dcschooley, 2021-04-22:
If the wire is too big, there is a risk of some the strands not making it into the hole and ending up somewhere they don't belong. The difference between 12AWG and 16AWG in voltage drop across 1ft of wire is somewhere around 5mV at 10A. 18AWG vs. 12AWG is 9mV. 20AWG vs. 12AWG is about 17mV. Pulling 10A in a single motor wire or into a single RoboClaw will almost never happen, and if it does, it won't be for very long. There is no good reason for anything over 16AWG. 20AWG is fine. 18AWG is probably optimum.

apollokit, 2021-04-23:
A'ight, 16AWG for the battery connections. Need to update the parts list and instructions accordingly

Closed 2023-09-25.

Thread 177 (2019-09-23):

PCB Rev E no electrical continuity between J6, J7 for pin 16 and all grounds

Roger-random, 2019-09-23:
### Pin 16 ###

AllPCB brought up a problem with rover PCB rev E: there is a partial traces to connect pin 16 on J6 (Raspberry Pi GPIO in) to its counterpart on J7 (Raspberry Pi GPIO out). However, it is incomplete so there would be no electrical connection. (Their diagram suggests a via at the location of the blue dot, but that would connect pin 13 to pin 16 which is not what we want.)

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

After this was brought up, testing with meter on a PCB made by JLCPCB confirmed the lack of continuity.

Current workaround: ignore the flaw and proceed, because J7 is unused.

But this will impede ability to extend the rover beyond JPL spec, a flawed J7 means modifications that need pin 16 would not be able to easily tap into Raspberry PI GPIO. Until this is addressed, using pin 16 will involve soldering to the back of J6 with fine wire and a steady hand.

### Ground ###

In addition to pin 16, testing with a continuity meter indicates all the GPIO ground pins are connected to PCB ground plane on J7 (RPI_GPIO OUT) but left floating on J6 (RPIGPIO_IN).

6
9
14
20
25
30
34
39

Current workaround: ignore the flaw, because data signals can ground through Raspberry Pi connected to J6.

But this should still be fixed in a future PCB rev. The ground plane reference may be unreliable in rev E due to the long distance (through ribbon cable, through Pi, through its power supply, etc.)

Also: since J7 is grounded, any extensions connected to J7 may find itself becoming the new path to ground. The device connected to J7 may not be able to handle it.

### Others ###

Continuity between J6 and J7 for all remaining pins check out OK.

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

ericjunkins, 2019-09-23:
The GND on J6 was left unconnected on purpose, I didn't want any chance of powering the RPi through the GPIO pins because it bypasses all the protection circuitry and on RPi.

You are correct it does appear that there is an unrouted trace between pin16 on J6 and J7. This pin is used to control the E-STOP on the RoboClaws from the RPi. I believe my intention was to remove it from the J7 connector all together, but must have just renamed the trace and deleted the part that was causing an error, but didn't remove the entire trace length.

"Current workaround: ignore the flaw, because data signals can ground through Raspberry Pi connected to J6.
But this should still be fixed in a future PCB rev. The ground plane reference may be unreliable in rev E due to the long distance (through ribbon cable, through Pi, through its power supply, etc.)"

What do you mean by the above statement? GND plane being unreliable in reference to what? You're worried that a data line isn't going to have correct reference to GND from that? I'm not sure I follow

Roger-random, 2019-09-23:
I'm worried that the voltage difference between ground pins of J6 (flowing through Pi, through lots of wires, and not connected to PCB ground) and J7 (PCB ground plane) will be significant enough to affect data signal integrity or induce a current flowing through a component that isn't intended to handle current.

I didn't know there was a reason for leaving ground unconnected until your reply, so thank you for that explanation. I confess I don't share the same concern in my own Raspberry Pi projects as I frequently power my Pi via its +5V/GND GPIO pins. But I can see and understand the reasoning for avoiding it.

What to do going forward will depend on which worry is more worrisome.

ericjunkins, 2019-09-23:
Usually logic levels for a 3.3V digital logic system are triggered at high at ~2.4V, I wouldn't expect any difference to be anywhere near that great to not register a digital logic from this.

Roger-random, 2019-09-23:
If I understand you correctly the planned actions are:

* Non-connected ground are intentional and will be left as-is
* Partial trace for pin 16 will be deleted, completely disconnecting that pin between J6 and J7.

Roger-random, 2019-10-11:
I nominate that the ground pins be connected so J7 can be used for logic level peripherals.

Scenario: Wiring up Adafruit I2C PWM board https://www.adafruit.com/product/815 to control RC hobby servos. This board has separate logic power (VCC) and servo power (V+) planes.

Servos are not wired into PCB 5V rail, they have their own independent power supply which is a pack of 4xAA for now, and will be something else later.

Logic lines can be wired to J7: Pin 1 for Raspberry Pi 3.3V for I2C pullup, pin 3 for I2C SDA, pin 5 for I2C SDL.

It would be easiest to use pin 6 for ground, but as it was deliberately not connected in J7, grounding requires a convoluted path requiring a separate wire to connect logic ground. This complication is  counter to the goal of making wiring easier with a rover mainboard PCB.

Roger-random, 2020-03-29:
Here's one example where lack of ground continuity caused issues: https://www.tapatalk.com/groups/jpl_opensource_rover/viewtopic.php?p=1390#p1390

Roger-random, 2020-04-08:
One idea that might satisfy both sides regarding ground: add a large (1 megaohm or maybe 10 megaohm?) resistor connecting signal ground and power ground planes on rover PCB. This would help converge (over time) voltage levels of separate ground planes without passing significant current from one plane to another.

JHPHELAN, 2020-04-25:
J6 & J7 connectivity
My original question was why there was a duplicate J7 connector at all.  My understanding was to be able to connect to the Pi GPIO pins for testing and additions.  In that case, I don't understand why ALL pins of J6 don't connect to J7 as it's mirror?

apollokit, 2021-04-11:
@ericjunkins I'm wondering the same thing as @JHPHELAN above....seems like j6 and j7 should just be 1-to-1 matches (well, except for ground I suppose)

Also note @dcschooley 's [latest updates to the pcb](https://github.com/nasa-jpl/open-source-rover/pull/198) has j6 GND pins all connected to the pcb ground plane. Is that now what's desired? seems to conflict with the discussion above.

dcschooley, 2021-04-11:
There's another set of discussions somewhere. Eric and I decided to power the Pi via J6 and get rid of the USB connector. I added the grounds to J6 to support powering the Pi.

apollokit, 2021-04-11:
Gotcha. Okay then, I guess that's handled. Good to have that recorded on this issue.

dcschooley, 2021-04-11:
The only place where J6 and J7 should still be different is at GPIO_GEN4/F_STOP. That's the signal the Pi uses to shut down the motors. It's connected at J6 but not J7. I think there was some discussion about that, and a good reason for not connecting it to J7.

apollokit, 2021-04-11:
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

this is the only thing I can find on this thread about not including E_STOP. No specific reason in there. Would be good to repeat that reason here if it was captured in discussion elsewhere. @ericjunkins

ericjunkins, 2021-04-11:
I'd recommend not connecting the estop pin from the J6 to J7, I don't think we'd want the ability to externally influence that pin from something other than the pi, if thats the question you're asking @apollokit. If we want the ability to control the e-stop from another source but the PI i'd recommending having a digital comparitor on the e-stop line that you can connect another input to for accomplishing that.
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
ericjunkins, 2021-04-12:
> ESTP (E-Stop) on the RoboClaws is active low. A simple 'And' gate would do the trick. Take one input from the Pi, the other off of the pin on J7,, and feed the output to the RoboClaws. There needs to be a pull-up on the J7 pin. I think this is worth doing. It won't hurt anything and will be dirt cheap.

Why have the AND gate and pullup on whatever is the external source of ESTOP? Why not OR gate them and have it pulled low. It seems like the other method assumes things about the state of what an external source would be state-wise (default up/down)

Royzinhouse, 2021-04-12:
Please, please delete me. I unsubscribed twice with no response

Have a joyful day.  Roy Sanders

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

Royzinhouse, 2021-04-12:
Please, please delete me. I unsubscribed twice with no response

Have a joyful day.  Roy Sanders

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

dcschooley, 2021-04-12:
> > ESTP (E-Stop) on the RoboClaws is active low. A simple 'And' gate would do the trick. Take one input from the Pi, the other off of the pin on J7,, and feed the output to the RoboClaws. There needs to be a pull-up on the J7 pin. I think this is worth doing. It won't hurt anything and will be dirt cheap.
>
> Why have the AND gate and pullup on whatever is the external source of ESTOP? Why not OR gate them and have it pulled low. It seems like the other method assumes things about the state of what an external source would be state-wise (default up/down) If you're AND gateing them together then you're assuing both the PI and external source agree that the system must be stopped, instead of both independently being able to stop it.

Setting ESTP low stops the motors, assuming I'm reading the documentation correctly. In that case, you need to AND the inputs and pull the possibly-unused input high to keep it from stopping the motors by accident. There's an internal pull-up in the RoboClaw when you have S3 set as ESTP.

ericjunkins, 2021-04-12:
> Setting ESTP low stops the motors, assuming I'm reading the documentation correctly. In that case, you need to AND the inputs and pull the possibly-unused input high to keep it from stopping the motors by accident. There's an internal pull-up in the RoboClaw when you have S3 set as ESTP.

Oh you can set it to be active high or active low, it doesn't matter.

ericjunkins, 2021-04-12:
@Royzinhouse notifications and emails from issues are managed on your account, you can follow these instructions to unsubscribe from a github issue:

https://docs.github.com/en/github/managing-subscriptions-and-notifications-on-github/managing-your-subscriptions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

ericjunkins, 2021-04-12:
Ah yeah it does allow S4 and S5 to be configured as estop ss well. All the digital pins can be logic 'inverted' using their Gui, I'm not sure if they give a software api to do so

apollokit, 2021-05-07:
Ok, so current plan is to connect s4 on the roboclaws (and a ground pin) to a small additional 2-pin header on the board so that 1) s4 can be used as a secondary e-stop and 2) it can be toggled by arbitrary other device. This is "e_stop 2"

Seems like the consensus on "e_stop 1" (from rpi) is to still have pin 16 disconnected between j6 and j7. Tbh, seems slightly confusing that now the only difference between j6 and j7 is pin 16....sure we don't want to just connect it? I'll leave it unconnected for now in the revF schematic, though it's always easy to add.

dcschooley, 2021-05-07:
Same thing for S5.

Leaving those pins unconnected between J6 and J7 keeps someone from being naughty and preventing the Pi from successfully driving E-Stop.

Pull-ups connected by jumpers to both S4 and S5 to keep the RoboClaws from inadvertently shutting down.

apollokit, 2021-05-07:
Why both s4 and s5? Just to have an option which to use?

dcschooley, 2021-05-07:
Extra flexibility, either for something else driving e-stop or one of the other functions. Maybe nobody will use it, but it doesn't cost anything and someone might find it useful. I would rather have it and not need it than need it and not have it.

+5. The jumper makes the pull-up independent of whatever you hook up to those inputs. The +3.3 is supplied by the Pi, and the RoboClaws need to function without the Pi.

Achllle, 2023-09-25:
resolved with the latest release.

Closed 2023-09-25.

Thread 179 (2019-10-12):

Orientation of wheel clamping hub S14A is important and should be clarified and depicted consistently

Roger-random, 2019-10-12:
RE: Wheel Assembly Build Doc PDF

Clamping hub S14A is flat on one side and the other side has a cylindrical protrusion. Diameter of this cylinder is smaller than wheel center, meaning it easily fits inside the wheel which will bolt against the surface of four tapped holes of S14A. As a result, the location of this wheel mating surface would vary by a few millimeters depending on whether S14A is bolted flat-side-in or flat-side-out. Both were depicted in documentation (list below.)

When bolted flat-side-in, with certain Traxxas wheels their mounting screw B5 extends far enough past hub S14A to make contact with face of motor E45 gearbox. In case of light contact, they will acts as brake pads. In case of strong contact, they will prevent the wheel from turning.

If this situation is not detected before motor calibration begins, applying motor power will strip gears in the gearbox.

Recommendation: Make all diagrams consistently flat-side-out and caution rover builders to examine their wheel mounting bolts to ensure their wheels can turn before applying motor power.

In Wheel Assembly Build PDF as of late August 2019:

_Figure 1: Drilling the Wheels_ shows flat side in
_Figure 3: Wheel Step 1_ shows flat side out
_Figure 4: Wheel Step 2_ shows flat side in

darpatel, 2020-01-07:
we also saw that using B4's instead of B5's when bolted flat-side-in solved the issue

ericjunkins, 2020-11-19:
Closing with changing to godiba motors this is not an issue anymore

Closed 2020-11-19.

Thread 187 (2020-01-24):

Control Board Schematic Issues

dcschooley, 2020-01-24:
I am making changes to the control board and have run into the following issues:

1. Test point T3 isn't connected to anything. This appears to be a placement error in the
schematic.
2. There are two J16 connectors (switch and battery out.) This makes KiCad complain about having multiple footprints when you update the PCB from the schematic. If you update the PCB from the schematic, "battery out" gets changed to J15 and the BATT+ connection changes to the unstitched battery. The polarity of the battery out connector gets switched if you tell KiCad to re-associate the footprints by reference, so don't do that.

mikcox, 2020-01-27:
@ericjunkins have you run into this before?  Can you shed any light here?

dcschooley, 2020-01-27:
I've fixed both of these in my local version. I'll do a pull request when I receive the updated boards and can verify that I didn't mess anything up.

There were two copies of J16 originally, and for some reason the PCB layout wanted to update it to J15. J15 is also a duplicate, but there isn't really a problem because it duplicates the battery input connector as a battery output connector. I deleted the extra J15 on the PCB and added a new connector in the schematic. Updating the board then works without KiCad complaining about a duplicate footprint.

By moving J16 to J15, it looks like the plan was to move the battery output connector from the switched battery voltage to an unswitched (no switch, diode, or resistor) connection. With my version, I kept it unswitched. I added a large trace on the edge of the board to connect J15 and the newly renumbered connector. It would be easy to move this trace to the switch.

My changes allow you to use quadrature encoders on the steering motors and also allow for homing switches. Jumpers are used to switch back and forth from the absolute encoder outputs from the voltage dividers to the quadrature encoders.

dcschooley, 2020-01-27:
I also deleted the extraneous trace and moved C2 as discussed in Issue #177.

ericjunkins, 2020-01-28:
Something must have gotten de-synced when I did an update and the schematic reference designators that caused this. @dcschooley also can you post the schematic for your changes?

dcschooley, 2020-01-28:
Here is the updated schematic. I didn't use nice symbols for J31-J34. That needs to be fixed. Those are the connectors where you use jumpers to select absolute or quadrature encoders. I deleted the test points for signals available on J31-J34.

[Control Board.sch.zip](https://github.com/nasa-jpl/open-source-rover/files/4123619/Control.Board.sch.zip)

ericjunkins, 2020-01-28:
That schematic is blank when I open it

dcschooley, 2020-01-28:
Ok, trying again. Here is the entire directory with everything but the gerbers.

[Control_Board_revised.zip](https://github.com/nasa-jpl/open-source-rover/files/4123790/Control_Board_revised.zip)

dcschooley, 2020-01-28:
My plan is to use shorting jumpers on J31-34 on the front of the board to select the encoder type. Unfortunately for the jumpers, the front of the board faces down when mounted in the rover, meaning the jumpers could vibrate loose and fall off of the board. The jumpers probably need to be on the back side. They are under RoboClaw 3 and might not fit that way. Moving them down and to the left above the serial cable connection is a pain. They probably need to be moved to the free space between RoboClaw 4 and RoboClaw 5.

ericjunkins, 2020-01-28:
Oh, no it was my mistake, my computer was opening the .Sch as an altium schematic, not a KiCAD schematic. It opened fine in the KiCAD project. Overall I think it will work fine, I have a few comments:

- Be aware that if you are using the quadrature encoder with your header adjustment that you are driving the output to the op_amp at what you have labeled "RCxENy_DIV". I expect the op-amp can handle that and be fine, but just be aware of it in case.

- Maybe think about doing a set of 3x4 headers instead of 4 individual 3 pin headers, https://www.digikey.com/product-detail/en/te-connectivity-amp-connectors/103817-2/A108960-ND/4031292, just easier to install and deal with

- It might be worth adding a noise filtering cap on the limit switch, whenever I use limit switches I always add a small like 0.1uF cap to the signal to help with the mechanical de-bouncing that happens in the switch. I

dcschooley, 2020-01-28:
RCxENy_DIV is the renamed output of the voltage divider circuit. There shouldn't be a connection between RCxENy and RCxENy_DIV unless I messed up the schematic (quite possible) or the builder messes up. RCxENy goes to the RoboClaw and is jumpered to either RCxENy_DIV or RCxENy_RAW. You don't need the voltage divider circuitry without the absolute encoders, so you could also leave out the op amps and the rest of the voltage divider. I like the capacitor and 3x4 header ideas.

dcschooley, 2020-01-29:
This should do it.

[Control Board F r2.zip](https://github.com/nasa-jpl/open-source-rover/files/4127888/Control.Board.F.r2.zip)

dcschooley, 2020-01-30:
Here is the updated schematic and board layout. Ignore the files I uploaded earlier.
[Control Board Rev F r2.zip](https://github.com/nasa-jpl/open-source-rover/files/4135699/Control.Board.Rev.F.r2.zip)

apollokit, 2021-04-10:
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

Confirming that these items look good in the latest schematic version. The subsequent conversation from this issue seems out of date though, I don't see any net  RCxENy_DIV in the latest version

dcschooley, 2021-04-10:
Are there still traces with that nomenclature? I did a revision of the boards, and actually had them made, where I was using limit switches and the built-in quadrature encoders on the ServoCity motors. This let me have 10 identical motors without having to deal with the absolute encoders. I eventually abandoned that idea after some problems with the limit switches. To make this work where you could use either the standard absolute encoders or the quadrature encoders with limit switches, I used used shorting jumpers to allow you to switch "modes." The input side of the jumpers had the _DIV naming for the outputs of the voltage dividers. Any traces with "_DIV" in the name are probably left over from that era.

apollokit, 2021-04-11:
I said in my comment that I _don't_ see any traces with _DIV. So no, none of that nomenclature seems to be left. I haven't fully groked your changes yet though.

Closed 2023-09-25.

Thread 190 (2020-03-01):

Feedback: 30AWG wire (X3, X4, X5, X6) too difficult to work with.

Roger-random, 2020-03-01:
As of August 2019, the wires for carrying wheel drive motor encoder data were 30AWG wires. For disambiguation there were four colors (X3 through X6). They are intended to connect to side-entry terminal blocks E3 on rover PCB.

Their small diameter are useful for routing through small gaps, helped by the flexible insulator. However, when trying to insert bare wires into E3, their small size is easily bent out of position. Once in position, they are so thin the screw-down terminal can't make solid contact, leading to electrical gremlins and/or wires falling out.

Akin's Australia and US rover build teams both independently came to the same conclusion these wire needed larger and more durable ends. (We didn't realize this until weeks after the fact.) The Australian rover got soldered headers, the USA rover received crimped-on connectors.

__Low-impact solution:__
Switch X3 - X6 to larger diameter wires.

__High-impact solution:__
For a future PCB revision, switch from side-entry terminal blocks to commodity wire-to-board electrical connectors. (JST-XH or similar.) It will require more up-front work to wire up the connector, though note in this case we ended up doing similar work anyway. The payoff is ease of disassembly for diagnosis and repair. For each wheel, one single plug by hand versus 6 individual wires and screwdrivers.

(Or do both: larger diameter wires AND wire-to-board connectors)

------

Log from Australia rover build team:

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

------

Photo of USA rover PCB:

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

ericjunkins, 2020-07-06:
Looking at making this change to upgrade the wire to be more accomidating to work with. Thinking about the following cables:
@Achllle I think I saw something where you were discussing motor currents and wire current, I tried digging through a few places I thought that discussion was and couldnt find it. Feel free to weigh in.

| Purpose | AWG | Link |
|:----------| :-----| :-----|
| Motor + | 16    | https://www.digikey.com/product-detail/en/cnc-tech/1569-16-1-0500-004-1-TS/CN645R-25-ND/9450426 |
| Motor  - | 16    | https://www.digikey.com/product-detail/en/cnc-tech/1569-16-1-0500-001-1-TS/CN642B-25-ND/9450423 |
| Encoder + | 24 | https://www.digikey.com/product-detail/en/nte-electronics-inc/WH24-06-25/2368-WH24-06-25-ND/11646871|
| Encoder -  | 24 | https://www.digikey.com/product-detail/en/nte-electronics-inc/WH24-05-25/2368-WH24-05-25-ND/11646835 |
| Encoder A | 24 | https://www.digikey.com/product-detail/en/nte-electronics-inc/WH24-04-25/2368-WH24-04-25-ND/11647079 |
| Encoder B | 24 | https://www.digikey.com/product-detail/en/nte-electronics-inc/WH24-09-25/2368-WH24-09-25-ND/11647824 |

dcschooley, 2020-07-07:
What's driving the change to 16AWG wire for the motors? It seems like overkill. 4ft of 20AWG has a voltage drop of 0.25 volts or so at 4A. 16AWG is less than 0.1 volt. The PWM going into the motors will change things a bit, but I'm not sure how much. Going with wire that size limits connector options.

Achllle, 2020-07-08:
It's not the voltage drop that's the issue, it's the current draw from the motors. The idea is to replace the default motors with beefier ones (which a lot of folks have done already) and current draw for a single motors could peak ~10A or more which is dangerous. Perhaps 18AWG is a middle ground?

dcschooley, 2020-07-08:
Voltage drop and heating due to current are two sides of the same coin. When sizing the wires, steady-state current matters more than transients. Except for the protective wire braid, our motor wires are basically exposed to air, as opposed to being enclosed in a wall or in conduit. That helps with any extra heat from transients and we are not worried so much about the total heat produced in the length of wire. The default battery is good for 8A at 16.8 V, so less than 135W total into the rover for a fully charged battery. 120W is probably a good number for when you've been driving for a while. That gives you 20W average for each drive motor. (The multimeter thing is good for 20A, so we can ignore that as a limit.)

The worst case is if the motors can pull the 20W at 6V, so that gives you a bit over 3A. My estimate of worst-case steady-state current is 4A. That's 4A into each motor as you drive across the prairie. At that current, assuming I did my math correctly, the power loss in each motor wire is 1W for 20AWG, and some fraction of that for bigger wires. At 10A, it's only 2.5W, which will only occur for a short time. I'm using the beefy 45 RPM Servo City planetary gear motors, and 10A into those motors for very long when stalled will destroy them. These motors come with 24AWG wire and JST PH series connectors, and anything much bigger is probably a waste of copper. (The battery has 16AWG wire.) The PH connectors are good for 2A steady state. My first thought when I was looking at the project was that the 20AWG motor wires were overkill, but they do help reduce the losses between the motor controllers and the motors.

I'll see if I can do a better characterization of the motors from the specs, just to see how they might look.

dcschooley, 2020-07-08:
So here's a screenshot of a table calculating voltage drop and wire losses for 1m length of wire. I got the resistances from some random place on the internet. I think the sweet spot is 20AWG for the motors. 22AWG for the motors would make it easier to find board connectors that would work for both the encoders and motors, but 20AWG will work.

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

Achllle, 2020-07-08:
I don't think everyone uses the default battery. I switched to a 9Ah 100C LiPo... The battery leads are 12AWG...

> 120W is probably a good number for when you've been driving for a while. That gives you 20W average for each drive motor.

Aside from using the battery upper limit as the starting point, I don't think I trust dividing that number by the number of drive motors. Loads are often very unbalanced, and it's also common to turn and drive at the same time.

> These motors come with 24AWG wire

Wow that seems crazy, are you sure of that? The [website](https://www.servocity.com/45-rpm-hd-premium-planetary-gear-motor) seems to show 16AWG. I have the GoBilda planetary gear motors and they come with 16AWG wires.

dcschooley, 2020-07-08:
> I don't think everyone uses the default battery. I switched to a 9Ah 100C LiPo... The battery leads are 12AWG...
>

The leads on your battery are so big because your battery has an extremely high discharge capacity. It appears to be a multi-rotor battery. The same size battery with a lower discharge capacity could get by with smaller wires.

> Aside from using the battery upper limit as the starting point, I don't think I trust dividing that number by the number of drive motors. Loads are often very unbalanced, and it's also common to turn and drive at the same time.

Dividing by six gives you an upper estimate for sizing the drive motor wires. Turning at the same time reduces the amount of current available for the drive motors, but that's a short-term impact and it wouldn't impact the size of the wires. If anything, it would make them smaller.

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

Yes, they have 24AWG wires. The JST PH connectors they come with are limited to 24AWG.

Achllle, 2020-07-09:
> Dividing by six gives you an upper estimate for sizing the drive motor wires.

If you assume that all drive motors draw the same current at all times. When there is more friction on one wheel or it's stuck and the other wheels are spinning freely, that one motor is going to draw quite a bit more.

In my case (and I think with quite a few people who decided to upgrade the battery), since the discharge capacity is so high, there's practically no limit on the 'current available'. For the case of a limited discharge, I agree with your point, but we want to support different batteries and discharge currents.

Regarding the wires on those motors: on the product page in the recommendations section they link the [16AWG wires](https://www.servocity.com/3-5mm-bullet-lead-fh-mc-300mm-length) and on that page they show the original motors so I'm still not convinced 24AWG is a good idea 🙂

dcschooley, 2020-07-09:
You are correct that some motors may be pulling more power than others for whatever reason, but 20W is still a good baseline for steady-state (average) power calculations. So the question is what happens if you start to deviate from normal.

Here are estimates of torque-speed and power-speed curves for those motors. I just took values from the provide torque-speed curves and calculated the output power. You are not going to get much more than 20W out of these motors no matter what you do. The current requirements are going to go up, but it will require more effort to calculate that and I'm not sure I could do it correctly right now. (I'm not entirely sure I got this right.) You certainly don't want to push more than 7A steady-state out of the RoboClaws for any extended period of time. Transients can certainly be higher than 20W, but as I said before, you really don't care about those WRT the wires from the RoboClaws to the motors.

If you look on the ServoCity page with the encoder versions of those motors, you will see the 24AWG wires and connectors. These are what you want for the drive motors.

I'm not saying to use 24AWG, I'm saying to stick with 20AWG unless there is a good engineering reason to make the wires bigger, and I'm not sure there is one. Tradeoffs include getting the wires from the motor to the body and connectors on the board. The blue connectors currently used for the battery connections are only good for 15A steady state. I am updating the PCB and will incorporate better connectors for the motors and encoders. The 24AWG-20AWG range of wire sizes is a sweet spot for connectors. We could use JST XA connectors and have a single connector for each motor/encoder combination. Anything larger than 20AWG means going up to JST VH connectors for the motors and hope they fit while using a different connector for the encoders. I'm also looking at incorporating an PI-interfaceable device for current and voltage measurements (per your request) and the AdaFruit device is only good for 15A steady state.

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

Achllle, 2020-07-09:
Thanks for the thorough analysis. I'm on the same page now!

apollokit, 2021-04-20:
Alright, so is the conclusion here to use 20 AWG for Motor +/-, and 24 AWG for the encoder wires?

Closed 2021-06-29.

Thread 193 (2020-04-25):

PCB fragile traces

JHPHELAN, 2020-04-25:
Having recently upgraded the 4 steering motors to the new specs and all 6 drive motors to the REV Robotics HEX motors I re-tuned them all using Basicmicro Motion Studio and they checked out ok (after I fixed a couple Molex connections that came loose.)  But when I tested it with the Xbox controller, the left side steering was paralyzed.  Logic demanded that it was a problem between the Pi and the RoboClaws.  Continuity check between the Pi and the PCB was intact.  Since communication with the RCs through the PCB was serial, there had to be a problem near RC5/132 that controlled steering motors 3 and 4.  [BTW, Section 4.2 figure 9 seems mis-labeled to me.  Front/Back are reversed and the steering motors are switched right/left when viewed from above.]  Examining the PCB I found a blown trace near RC5.  Above RC5 and next to RC3 in attached pic.  The two red wires near the fried trace are jumpers from a previous blown trace to the LED display.  The second pic shows the repair (prior to cleaning up the flux and solder stains).  Looking at the Gerber of the PCB (I have Rev D.  Not sure what the changes are to the current Rev E) it seems that the traces are very narrow and wouldn't be able to handle much current making them more susceptible to failure.  Would suggest increasing the width of all traces as much as possible on any future revision.  (along with a number of other changes, but that's a different story.)
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

ericjunkins, 2020-04-26:
Can you link the motors you use please. If you are using a motor that pulls significantly more power than the initial ones then yes I could see that happening.

JHPHELAN, 2020-04-26:
The blown trace is not a motor power trace, but the serial path to the RC.
The motor is the standard OSR upgraded steering motor:
[https://www.servocity.com/45-rpm-hd-premium-planetary-gear-motor](url)

ericjunkins, 2020-04-26:
The traces you show jumped in the above picture do not go to the roboclaw, nor are they serial lines. And i don't think what is jumped herewith wires is correct as well. It appears that the section you are jumping is for the J22 Connector, J10 connector, and C7 capacitor I believe. The First picture shows  the follwing jumpers:

ericjunkins, 2020-04-26:
The traces you show jumped in the above picture do not go to the roboclaw, nor are they serial lines. It appears that the section you are jumping is for the J22 Connector, J10 connector, and C7 capacitor I believe.

 J22 pin 4 (+5V) to

JHPHELAN, 2020-05-06:
@ejunkins
Sorry for the slow reply.  The blown trace is to J22 the +5V which powers the encoder for the Left front steering motor (mis-labeled Right in this version D of the board) so the RoboClaw couldn't read the encoder.

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

ericjunkins, 2020-05-06:
@JHPHELAN right that's the trace I mentioned above. I am wondering if there was a short in your system, especially if you look closely at this picture, you can see that you have a bit of exposed wiring on the +V line, which is directly next to the GND
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

In order to blow the trace that did you would have to pull in excess of 1.5Amps, which that encoder would never come anywhere close to without a short somewhere.

ericjunkins, 2020-06-25:
Closing from non-issue

Closed 2020-06-25.

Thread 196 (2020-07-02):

DROK current+voltage sensor replacement

Achllle, 2020-07-02:
We currently use the DROK multimeter with screen. There's no interface other than the display for it so we can't read the values from the Raspberry Pi or Arduino.
It would be useful to access these values so we can log them. Brief current spikes might not show up and are hard to see. We could still display the real-time values on the LCD display.
You can get a digital sensor for under $10.

dcschooley, 2020-07-09:
It will be easy to add this: <https://www.adafruit.com/product/4226>. I'm assuming this part is decent. Is there anything better?

This device would become part of the incoming power circuit, so it would be a requirement. I'm wondering if it would make sense to replace the DROK with a small display driven by this thing and the PI.

ericjunkins, 2020-07-09:
@dcschooley Right I was thinking about that too, that i dont necessarily want to get rid of entirely a way to display voltage and current etc to the user, would be good to have both the ability to read  the values like with the adafruit part you mentioned, and have a small display

dcschooley, 2020-07-09:
I think you definitely need to have a user-viewable display. Part of it is educational, the other is you simply need to know what is happening with the rover. Having the DROK is useful during testing so that you don't let the battery voltage to get too low. Losing that would be slightly annoying if the PI wasn't up and running yet. One advantage of a controllable display is that the PI could display warning messages if the battery voltage gets too low or the current gets too high, preferably in a different color.

dcschooley, 2020-07-09:
Here's a possibility for socketing the power connection for the Adafruit device: <https://www.digikey.com/product-detail/en/samtec-inc/HPF-02-01-T-S/SAM9491-ND/6678228> and <https://www.digikey.com/product-detail/en/samtec-inc/TSW-202-07-T-S/SAM10858-ND/2686027>

apollokit, 2021-04-09:
> I think you definitely need to have a user-viewable display. Part of it is educational, the other is you simply need to know what is happening with the rover. Having the DROK is useful during testing so that you don't let the battery voltage to get too low. Losing that would be slightly annoying if the PI wasn't up and running yet. One advantage of a controllable display is that the PI could display warning messages if the battery voltage gets too low or the current gets too high, preferably in a different color.

Another potential option here is that we could just make a little web app that is easy for people to run, which collects and displays telemetry from the rpi. Definitely not as reliable as a built-in display, and wouldn't currently work when out of wi-fi range.

apollokit, 2021-04-09:
Why don't we just include the [TI chip](https://www.ti.com/lit/ds/symlink/ina260.pdf) on the control board directly for rev F? Seems like a more straightforward solution rather than having a daughter board that can mechanically fail.

dcschooley, 2021-04-09:
> Why don't we just include the [TI chip](https://www.ti.com/lit/ds/symlink/ina260.pdf) on the control board directly for rev F? Seems like a more straightforward solution rather than having a daughter board that can mechanically fail.
>
> Plus I think it would be fun to do the work of including it :)

That's a really good idea. Unfortunately you can only get it in a surface mount package. Doing surface mount would be a bit much to ask newb solderers.

ericjunkins, 2021-04-09:
Yeah I guess it depends on where we sit on the line of difficulty vs functionalities. It's a Tssop 16 package which is at least reasonable, something like qfp64 would be out of the question.

https://jeelabs.org/book/1513c/index.html

Here's a little breakout board I've used things similar to this for breadboard testing of surface mount components. One could potentially include these, and have it attach via the 0.1 inch headers, that way you have essentially unlimited tries and aren't ruining the main pcb

dcschooley, 2021-04-09:
But in that case wouldn't it make the most sense to just use the AdaFruit board?

dcschooley, 2021-04-09:
Maybe we just go ahead and solder the Adafruit thing into the PCB like nature intended. Yes, you do have to unsolder it if it goes bad, but it's just a few pins.

apollokit, 2021-04-10:
ah yes, agreed on the surface mount aspect. I didn't think about that.

@dcschooley what do you mean by "solder the adafruit thing"? solder the whole breakout board?

dcschooley, 2021-04-10:
The Adafruit board comes with two pin headers that you solder onto the board in the orientation you want. One is low current signaling that can go into any appropriate socket and the other is for the high current connection. There was some discussion early on about this part regarding how to connect it to the PCB. The easiest way would be to solder the high-current pins directly to the main PCB. The ina260 would be permanently attached at this point. The downside is what happens if the ina260 craps out and you have to unsolder it. I did some checking on the Dici-Key web site and found some socket/pin combinations that were supposed to work together and would also support the necessary current. The ones I ordered did not fit together correctly, even though Digi-Key said they were supposed to. I'm sort of at the point of saying solder the whole thing down and be done with it. Fixing a blown chip would still be easier than trying to deal with the surface mount.

JHPHELAN, 2021-04-11:
I like the DROK and the Adafruit breakout board.  I rearranged my power sequence to:
battery/wall wort > lighted push button > DROK > remote kill switch > PCB.
This way I can see if the battery is adequate before turning on the system with the kill switch.
Surface mount tech is a bit much to ask of us amateurs.
I like the ease of the Adafruit breakout board so we should make a place for it on the PCB.
The next question is how to handle the 8 signal pins?  Jumpers/cable to pins on the secondary ribbon cable connector?
Route them through the PCB to appropriate pins on the Pi?  Which pins?  We should standardize this to avoid confusion with future as yet unknown additions.  What software?  Is there a ROS node for this?  What kind of display?  The current LED display is crude and power hungry.  Use the HDMI port?  The Adafruit 2407 7" HDMI works well.  [https://www.adafruit.com/product/2407](url) or one of their several LCD displays such as [https://www.adafruit.com/product/2050](url)?  A high-res display along with a camera would make for real telepresence.  There are apps to make a cell phone into a USB display or camera.  Don't know if they'll both work at the same time.

Achllle, 2023-09-25:
We now have the DROK and the INA260 so I consider this resolved.

Closed 2023-09-25.

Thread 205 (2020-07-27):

Add filter capacitors to quadrature encoder connections

dcschooley, 2020-07-27:
The Servo City HD Premium Gear Motors with encoders have a capacitor acting as a snubber on the encoder board. This capacitor couples the 20kHz PWM voltage from the RoboClaws into the encoder signals. The 20kHz noise causes errors, showing up as extra pulses, when the RoboClaws read the encoders. BasicMicro recommends 0.01uF capacitors on the encoder lines to filter out the 20kHz noise. Locations for these capacitors need to be added to the control PCB.

The snubber circuit is a poor design that supposedly shows up in similar motors that have built-in encoders. The extra capacitors can be considered optional for motors that do not need them, but adding the filtering should not impact motors that do not need them, and the extra filtering is not a bad idea.

The 0.1uF capacitors already in use on the board are too large for this purpose and filter out the encoder signals entirely at high motor speeds. The 0.01uF capacitors eventually specified for the project should have a different form factor to keep them from getting mixed up with the 0.1uF capacitors.

SallyTYT, 2022-09-28:
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

0.01uF capacitors on the encoder lines really help reduce the jitters in speed measurements on the RoboClaw. Before I added the capacitors, there were huge jitters in the speed measurements on my 7# and 8# drive motors, leading to the velocity control not working. And the capacitors helped solve this issue.

Achllle, 2023-09-25:
I take it that this issue is solved with the latest PCB design for v2. If not, let me know and we can reopen.

Closed 2023-09-25.

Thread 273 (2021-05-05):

Update BOM/docs with a good alternative for Traxxas 5374X wheels

apollokit, 2021-05-05:
We're encountering out-of-stock's on the Traxxas wheels, for example https://opensourcerover.slack.com/archives/C01D07KNKJM/p1620218389012800

They're currently out of stock on the [dollarhobbyz website link](https://www.dollarhobbyz.com/collections/all/products/traxxas-2-talon-tires-gemini-black-chrome-wheels-5374x) from the BOM, though they can be found [on amazon](https://www.amazon.com/TRAXXAS-5374X-BRUSHLESS-REVO-WHEEL/dp/B00C5T2GRY).

Getting the impression that supply for these wheels is dwindling

Would be good to have a solid alternative for them in the docs/BOM.

1) find an alternative (perhaps taking advantage of the new gobilda motors)
2) update docs/BOM

Achllle, 2021-05-11:
From @dcschooley:

> A question came up somewhere because the default wheels are out of stock. I get mine from Amazon: [Dave's Wheels](https://www.amazon.com/gp/product/B06XS6V7T9/ref=ppx_yo_dt_b_asin_title_o00_s00?ie=UTF8&psc=1) They work great. They use a standard 17mm hex mounting. I remove the red ring so that I can remove the factory hubs and replace them with my own design, but the factory hubs could be made to work, I think.

These are the same diameter.

mredmon63, 2021-05-18:
apollokit, are you talking about the Rex 8mm hex output shaft gobilda motors?  I bought two 5203-series motors to evaluate because the BOM motors (5202-series) have been out of stock for six weeks and are not expected for another 5 weeks.
Do you have a recommendation to integrate the Rex 8mm hex output shaft to a wheel?

apollokit, 2021-05-23:
Hmm. Not sure. There's [this hub](https://www.gobilda.com/1309-series-sonic-hub-8mm-rex-bore/) that also has a square pattern for the holes, similar to the [hub we use](https://www.servocity.com/6mm-bore-clamping-d-hub-tapped-0-770-pattern/) to attach to the wheels.

But i don't think the square size is compatible, just from quickly comparing the two. *Do* double check my math on that

Besides that, I would:
- look around for some adapter between the Rex 8mm shaft and the 6mm hub we used...
- or 3d print a custom adapter

@Achllle , thoughts?

I hope this out-of-stock issue is due to current global supply chain issues...

Achllle, 2021-05-24:
> look around for some adapter between the Rex 8mm shaft and the 6mm hub we used...

Would love this scenario, but I just haven't found the parts to do this yet. There seems to be some standardization in the RC cars world, but I've never found documentation for that.

mredmon63, 2021-05-26:
[17mm Hex Adapter.zip](https://github.com/nasa-jpl/open-source-rover/files/6547958/17mm.Hex.Adapter.zip)
This is the simple printed adapter I am using to integrate 17mm wheels to the 7mm hex shaft on the Gobilda motor: https://www.gobilda.com/5203-series-yellow-jacket-planetary-gear-motor-26-9-1-ratio-24mm-length-8mm-rex-shaft-223-rpm-3-3-5v-encoder/
In my opinion this motor is a better option than the BoM motor (5202 series) since it has all-metal gears.  I also prefer the larger diameter hex output shaft over the smaller d-shaft of the 5202 series.  My alternative requires a larger (36mm) clamping mount, M4 0.7mm x 22mm screws (6) and an M4 14mm dia washer (McMaster).
These are the wheels I chose:
https://www.amazon.com/gp/product/B06XS6V7T9/ref=ppx_yo_dt_b_asin_title_o01_s00?ie=UTF8&psc=1
I do not like the looks of them as much as the BoM wheels, but they are comparable.
I went with the alternate motors and wheels due to lack of availability of the BoM motors and wheels.
Best,
mark

Achllle, 2022-02-07:
@dcschooley just discovered [these Servocity 12mm hex adapters](https://www.servocity.com/hubs-for-12mm-hex-drive-wheels/#actobotics) which might open up the search for new RC wheels without awkward attachment schemes

Achllle, 2023-09-25:
should be resolved as soon as we can get our hands on the Gobilda ones!

Closed 2023-09-25.

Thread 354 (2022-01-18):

JST-XH connectors not included in BOM or instructions for GoBilda encoder connections

Achllle, 2022-01-18:
- [ ] add 4 pin JST-XH connectors to BOM
- [ ] add to instructions in right place

JoshSharpe, 2022-01-24:
The GoBilda motor requires these and 3.5mm MH-FC bullet connectors for the M+/- wire that already exist. Usually I'd open a new issue but since these are closely related and should be updated together I wanted to just piggy back off this one.

Depending on instructions, there might be additional parts. I'm planning on using 2.54 mm connector on the other end of the motor to plug into the PCB. I'm not sure if that is what others did. But it seems like that will be more reliable/secure.

Achllle, 2022-01-24:
> The GoBilda motor requires these and 3.5mm MH-FC bullet connectors for the M+/- wire that already exist. Usually I'd open a new issue but since these are closely related and should be updated together I wanted to just piggy back off this one.

Yes, we should probably add these in. They are optional, since you can just solder them together as well without connector.

> Depending on instructions, there might be additional parts. I'm planning on using 2.54 mm connector on the other end of the motor to plug into the PCB. I'm not sure if that is what others did. But it seems like that will be more reliable/secure.

We probably won't make any more updates to existing wiring given the upcoming change to the new PCB 2.0 version. See #pcb-rev-f on slack for the latest updates. Essentially we're replacing the corner motors with servos and the PCB is entirely re-architected. We're aiming for a fall release this year.

Achllle, 2023-09-25:
closing since no longer relevant with latest update

Closed 2023-09-25.

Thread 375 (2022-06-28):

[Bug Report] PCB Assembly Readme.md: Controller Board's JST connector needs to be connected backwards

SallyTYT, 2022-06-28:
The opening in the pins on the JST connector should face OUTWARD as shown below.
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

https://github.com/nasa-jpl/open-source-rover/tree/master/electrical/pcb_assembly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

ericjunkins, 2022-06-28:
Just to clarify, this ticket is to point out that the connector _should have_ been designed to be put on 180 degrees from what it currently is correct? If so yes, that was a design oversight, and in our current work in redesigning a lot of the electrical system, including a new set of PCBs we will make sure to verify these things.

https://github.com/nasa-jpl/open-source-rover/pull/198

SallyTYT, 2022-06-30:
> Just to clarify, this ticket is to point out that the connector _should have_ been designed to be put on 180 degrees from what it currently is correct? If so yes, that was a design oversight, and in our current work in redesigning a lot of the electrical system, including a new set of PCBs we will make sure to verify these things.

Yes.

I found the Arduino shield board couldn't be powered correctly if following the current guidance, then found this issue. The cable E26 given by the BOM list is as the left condition in the description, which means one of the directions is incorrect. I tend to think that generally a connector opening is towards the outside of the PCB, thus, the connector on the control board is the one.

ericjunkins, 2022-06-30:
I am feeling confused still. Is the issue:

1). The directions are incorrect and one of the connectors you think needs to be spun 180 degrees to electrically make it work

OR

2). The board _design_ has two different orientations of connectors and that is awkward because of convention. (I know this is true and being addressed).

SallyTYT, 2022-06-30:
I mean 1) The directions are incorrect and one of the connectors I think needs to be spun 180 degrees to electrically make it work.

We just need to spin the connector itself. I don't think you need to adjust the electrical part of the PCB design. But perhaps you can mark the correct direction on the PCB.

SallyTYT, 2022-07-01:
I painted how the cable direction affects the direction of the connector, as shown in the following figure. The cable we bought is in the right condition.

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

> We just need to spin the connector itself. I don't think you need to adjust the electrical part of the PCB design. But perhaps you can mark the correct direction on the PCB.
I'd like to correct that the PCB layout doesn't need to be adjusted, and the schematic and mark may need to be adjusted.

Achllle, 2023-09-25:
closing since no longer relevant with latest update

Closed 2023-09-25.

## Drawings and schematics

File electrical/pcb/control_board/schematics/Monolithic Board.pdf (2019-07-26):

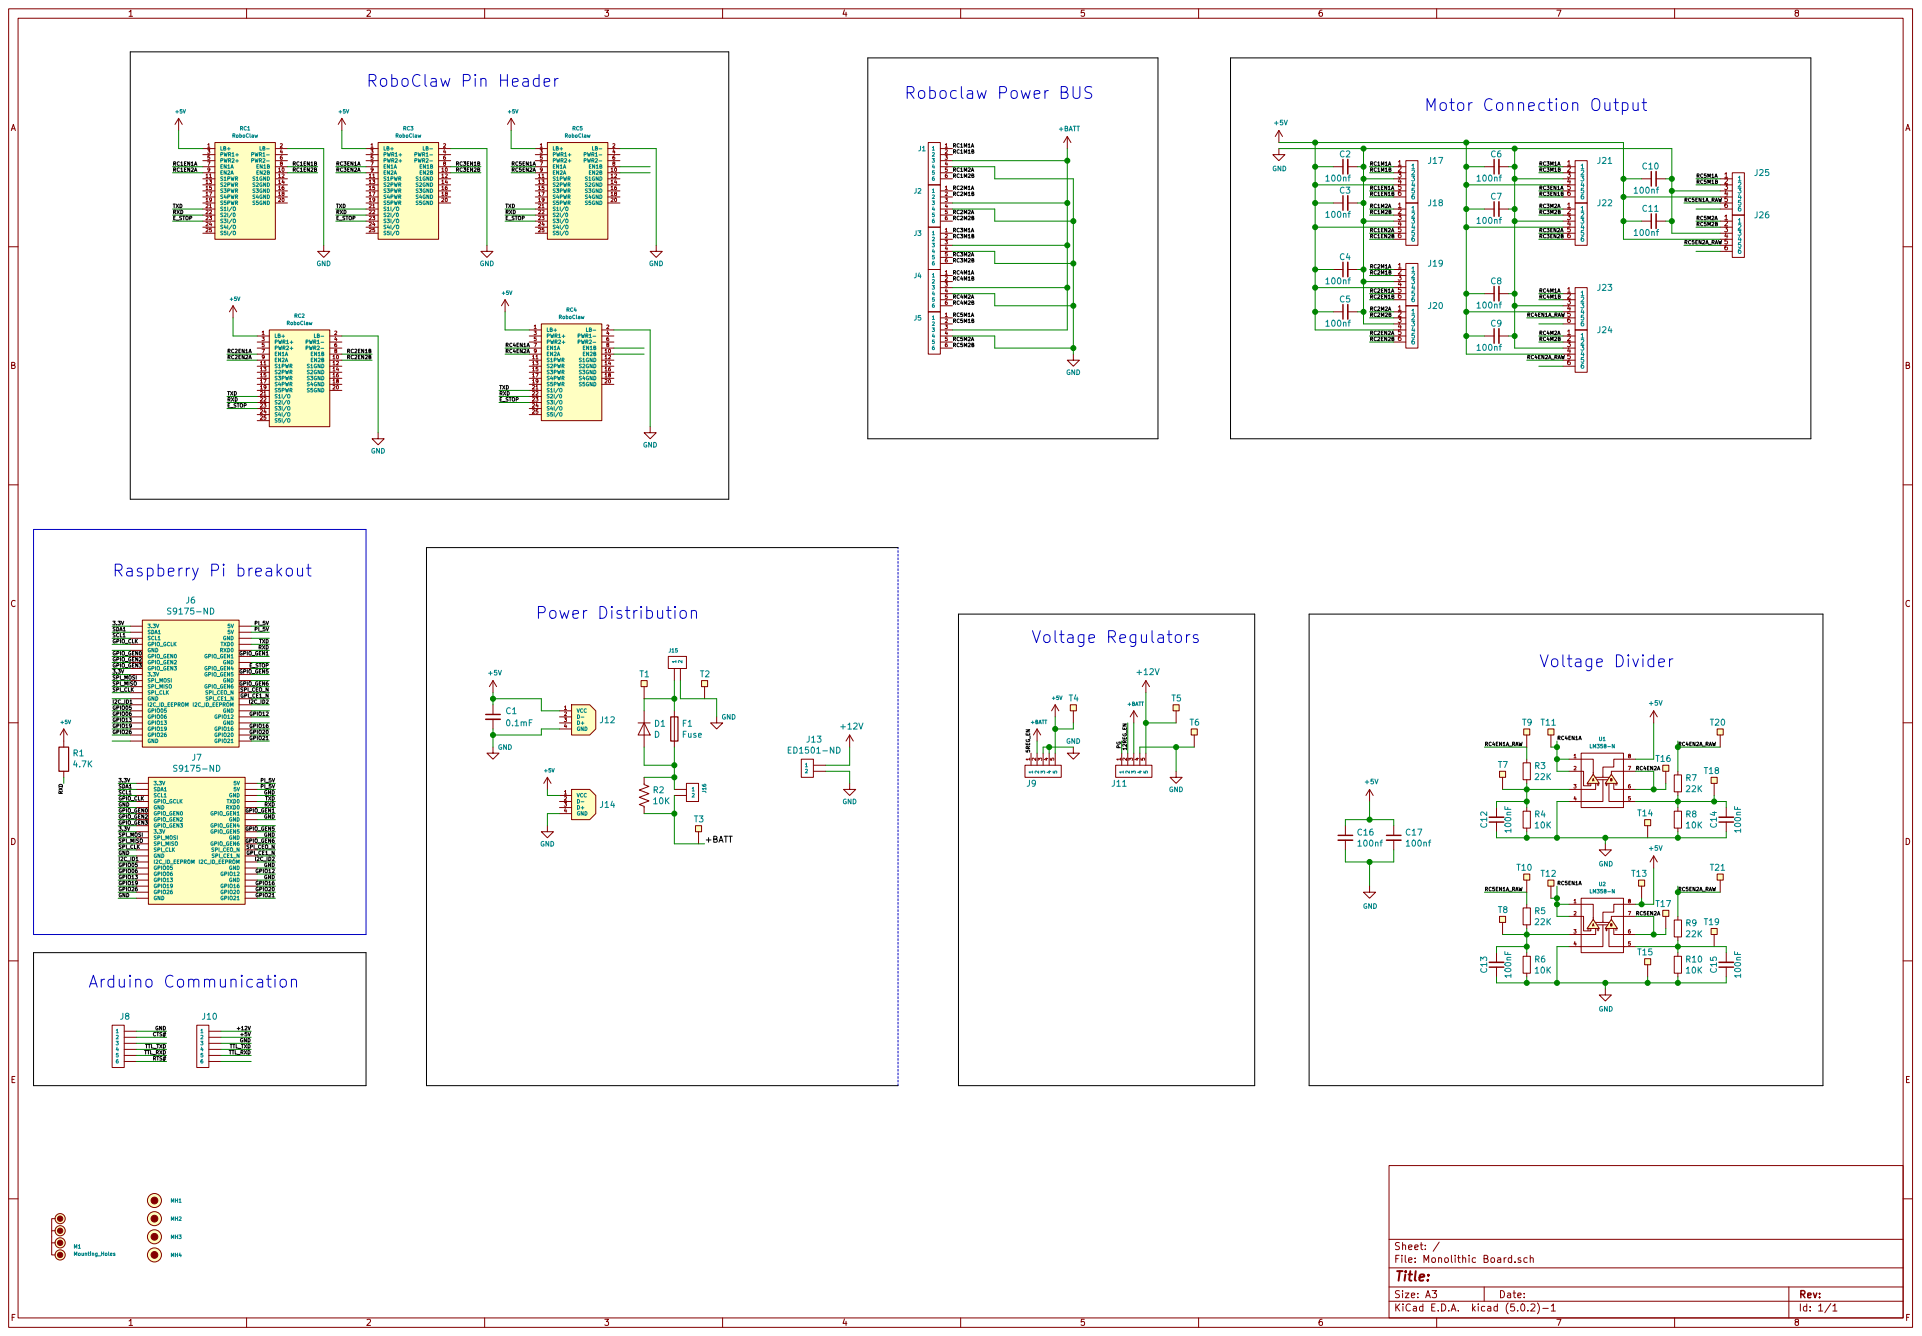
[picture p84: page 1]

Id: 1/1 Title: File: Monolithic Board.sch Sheet: /

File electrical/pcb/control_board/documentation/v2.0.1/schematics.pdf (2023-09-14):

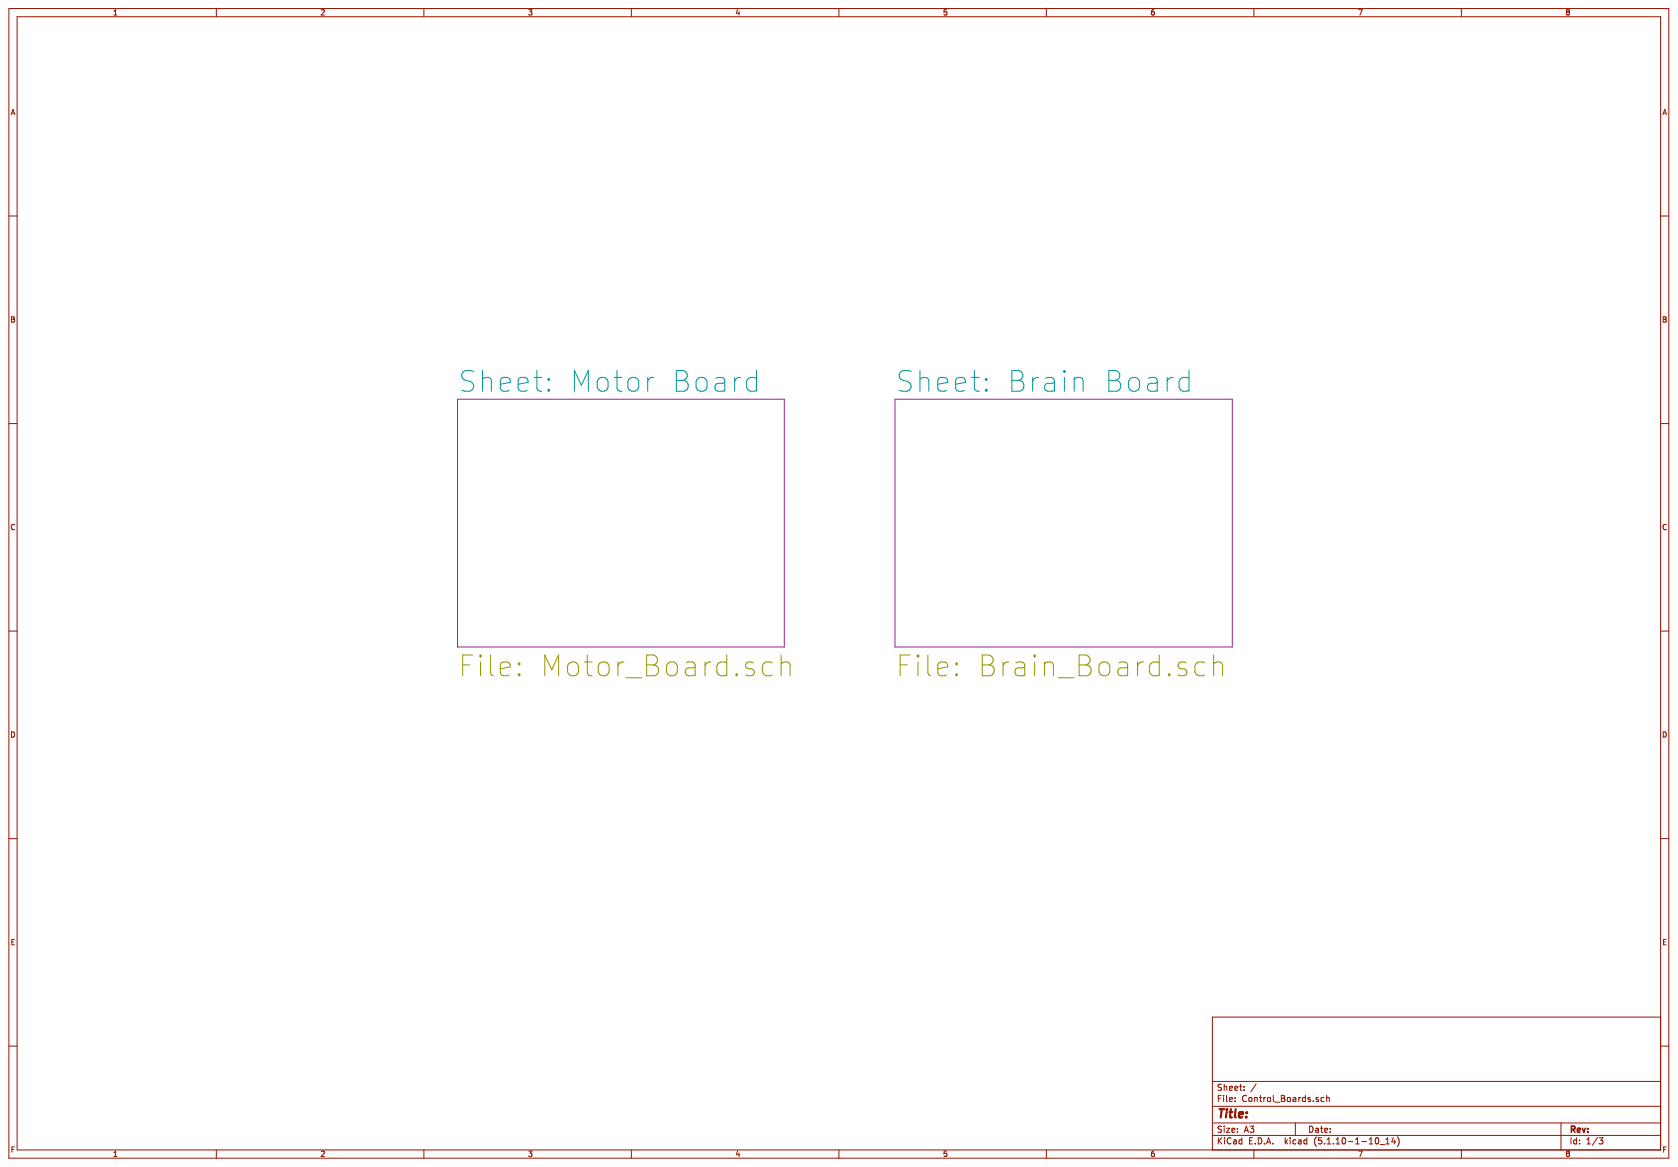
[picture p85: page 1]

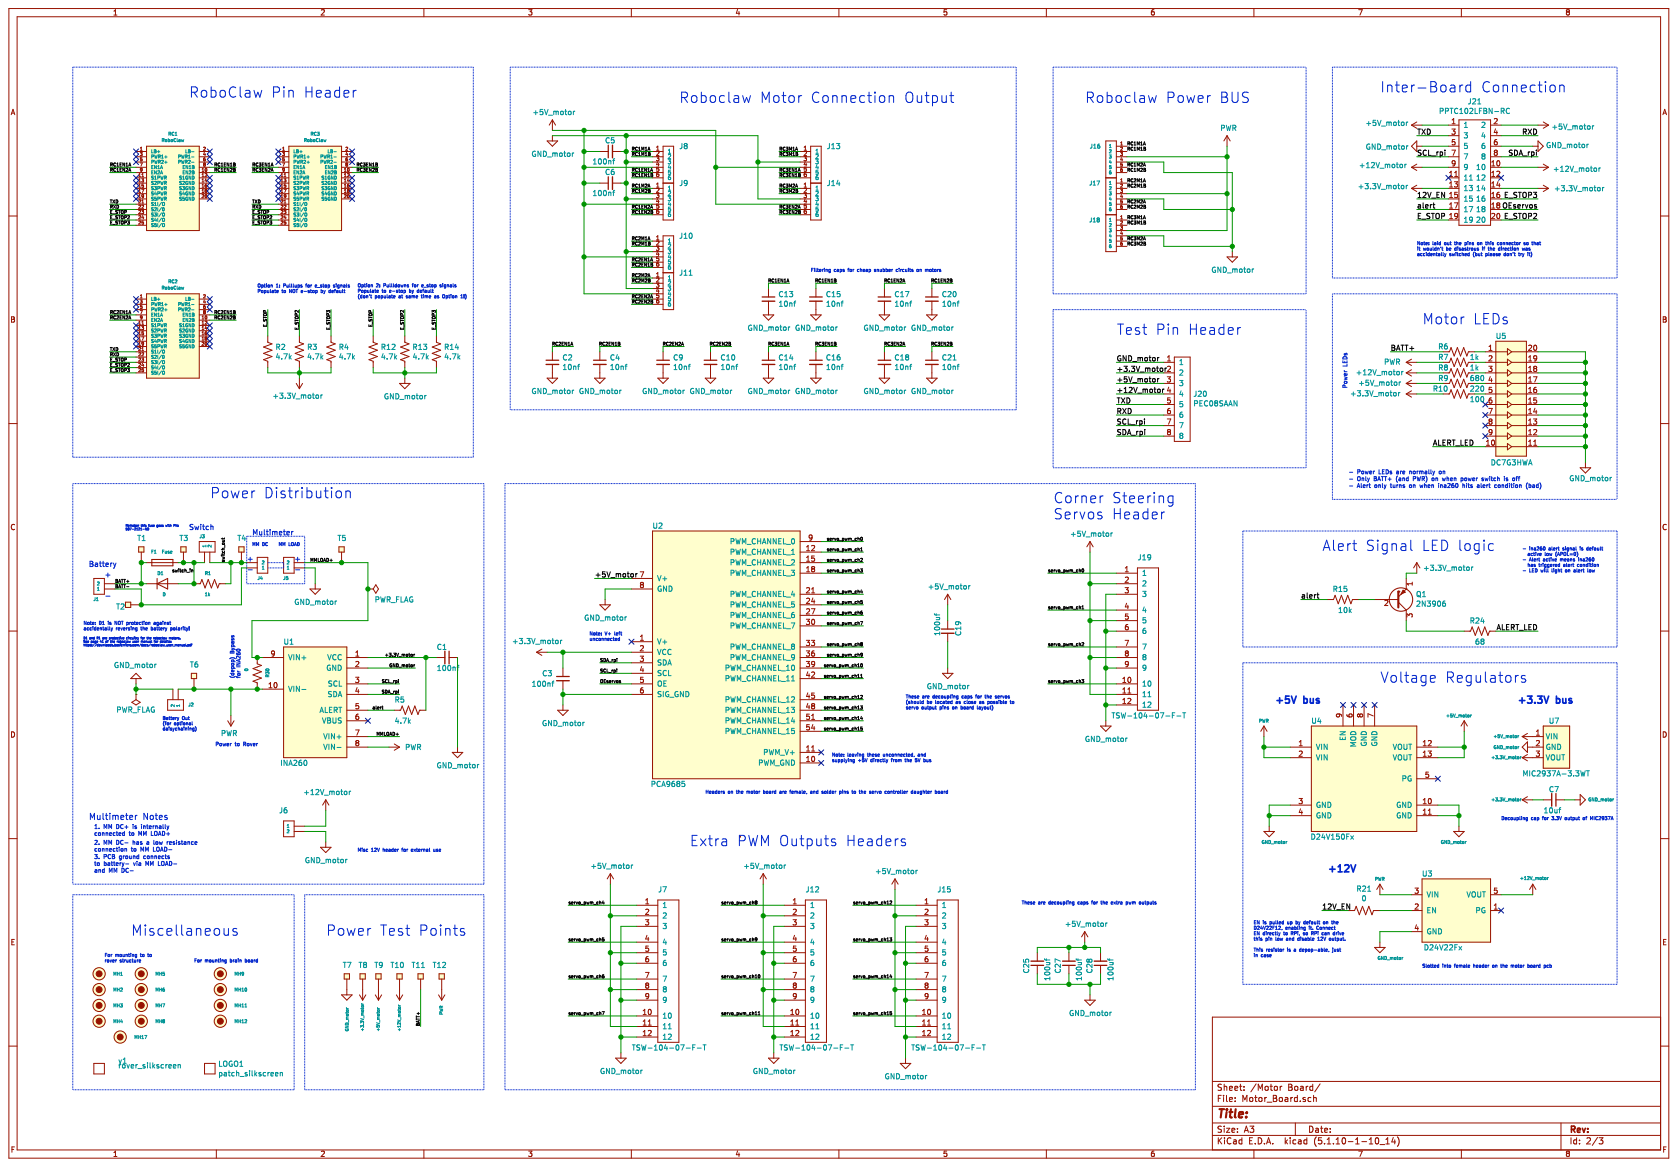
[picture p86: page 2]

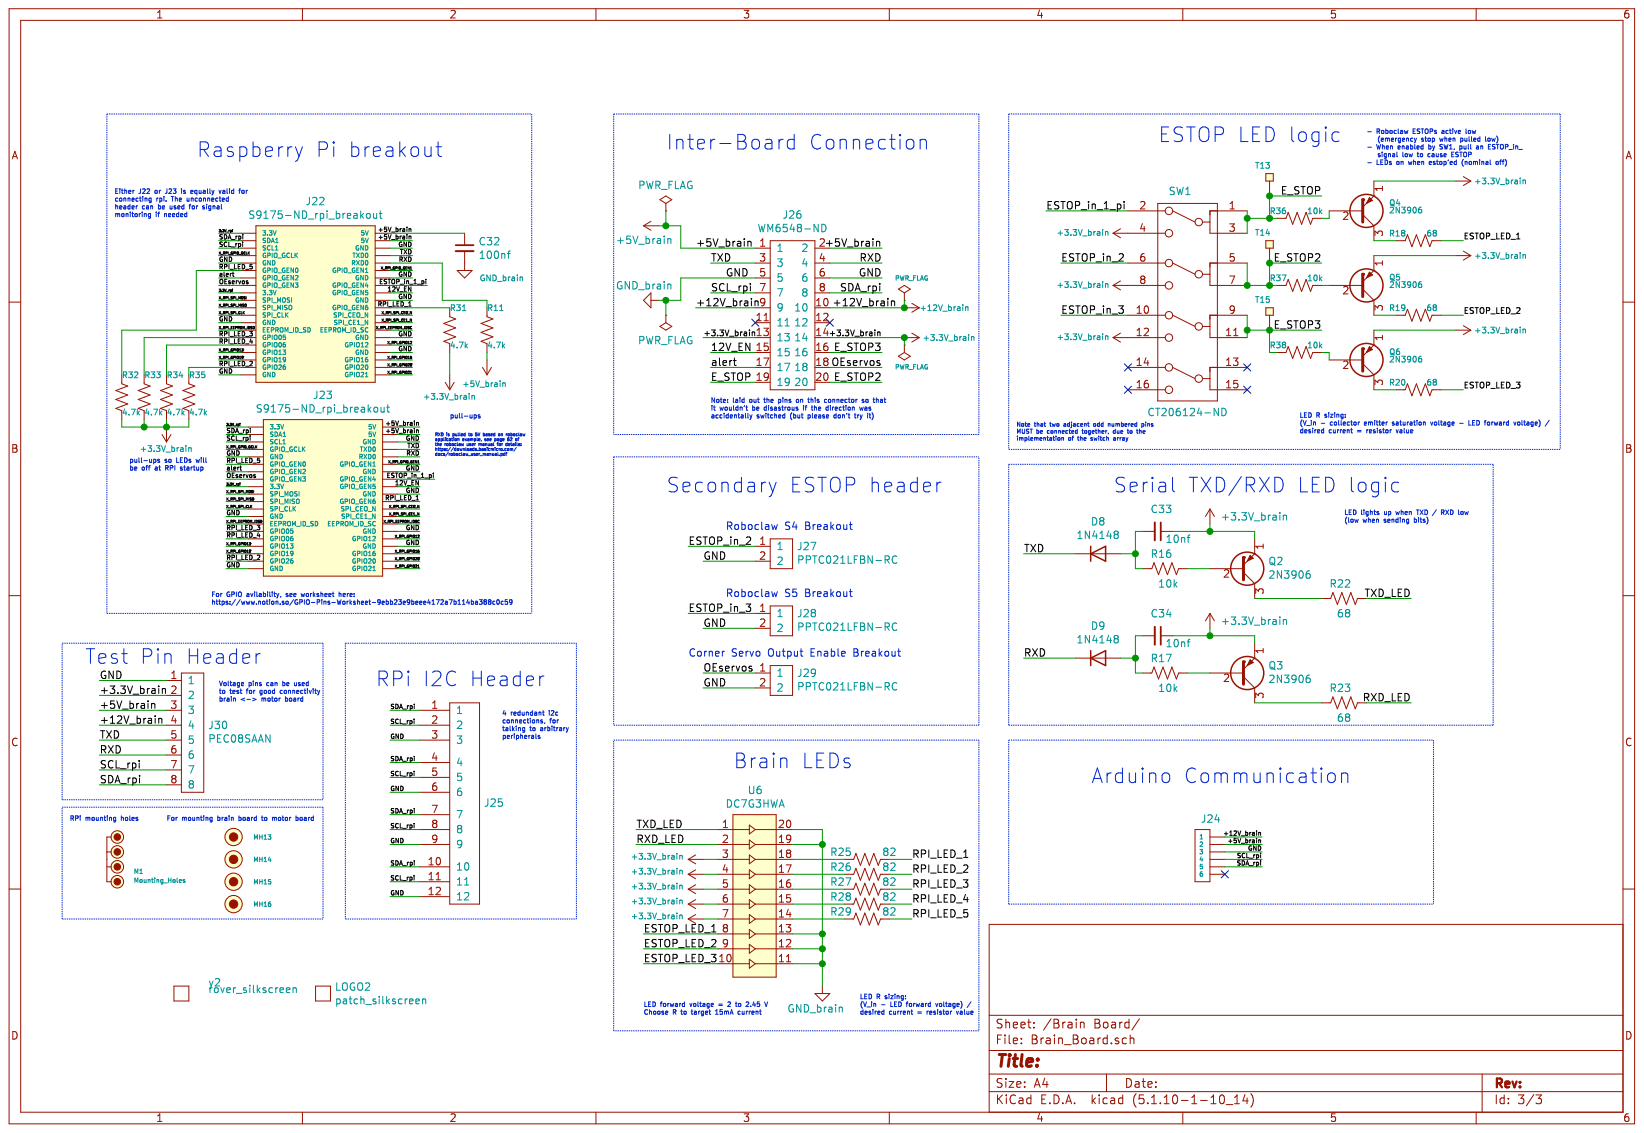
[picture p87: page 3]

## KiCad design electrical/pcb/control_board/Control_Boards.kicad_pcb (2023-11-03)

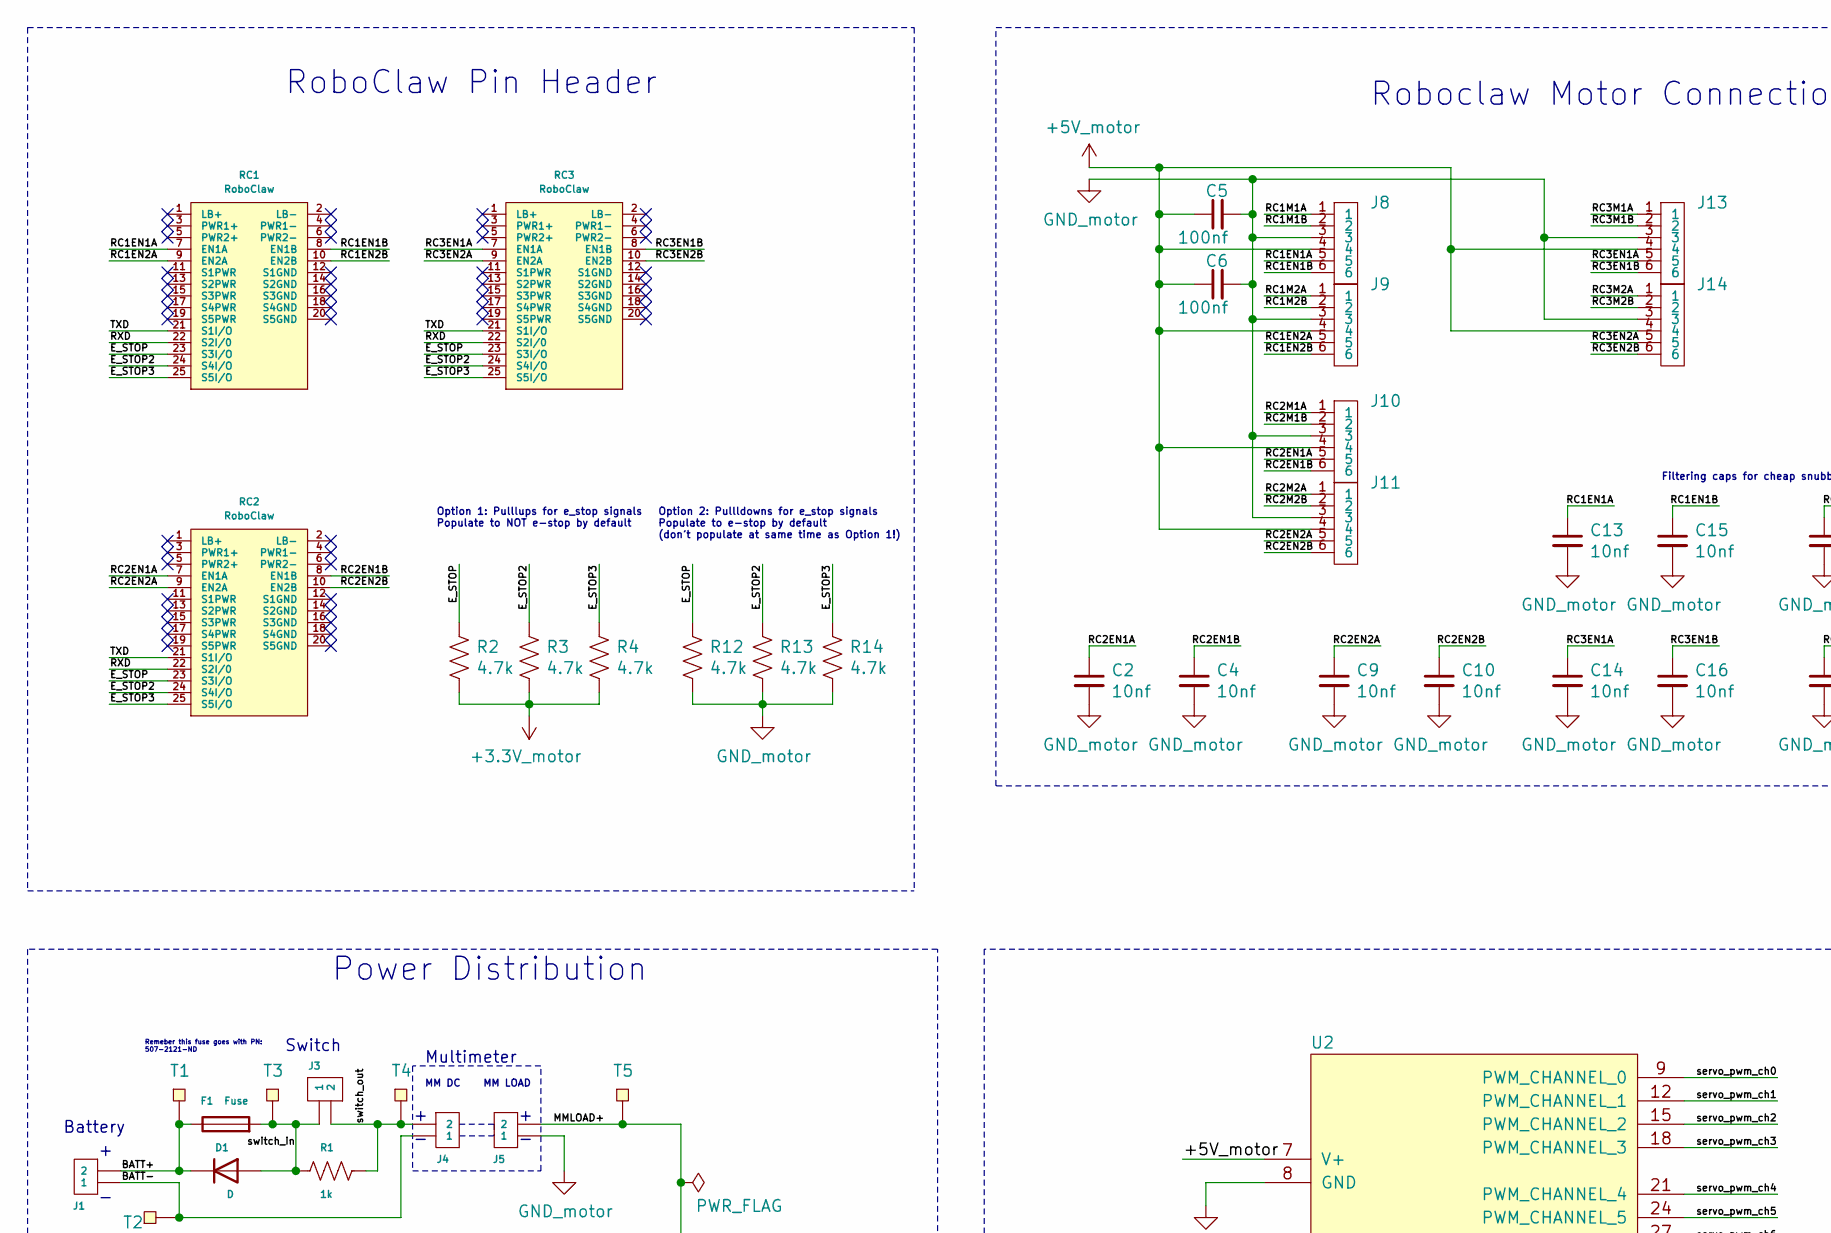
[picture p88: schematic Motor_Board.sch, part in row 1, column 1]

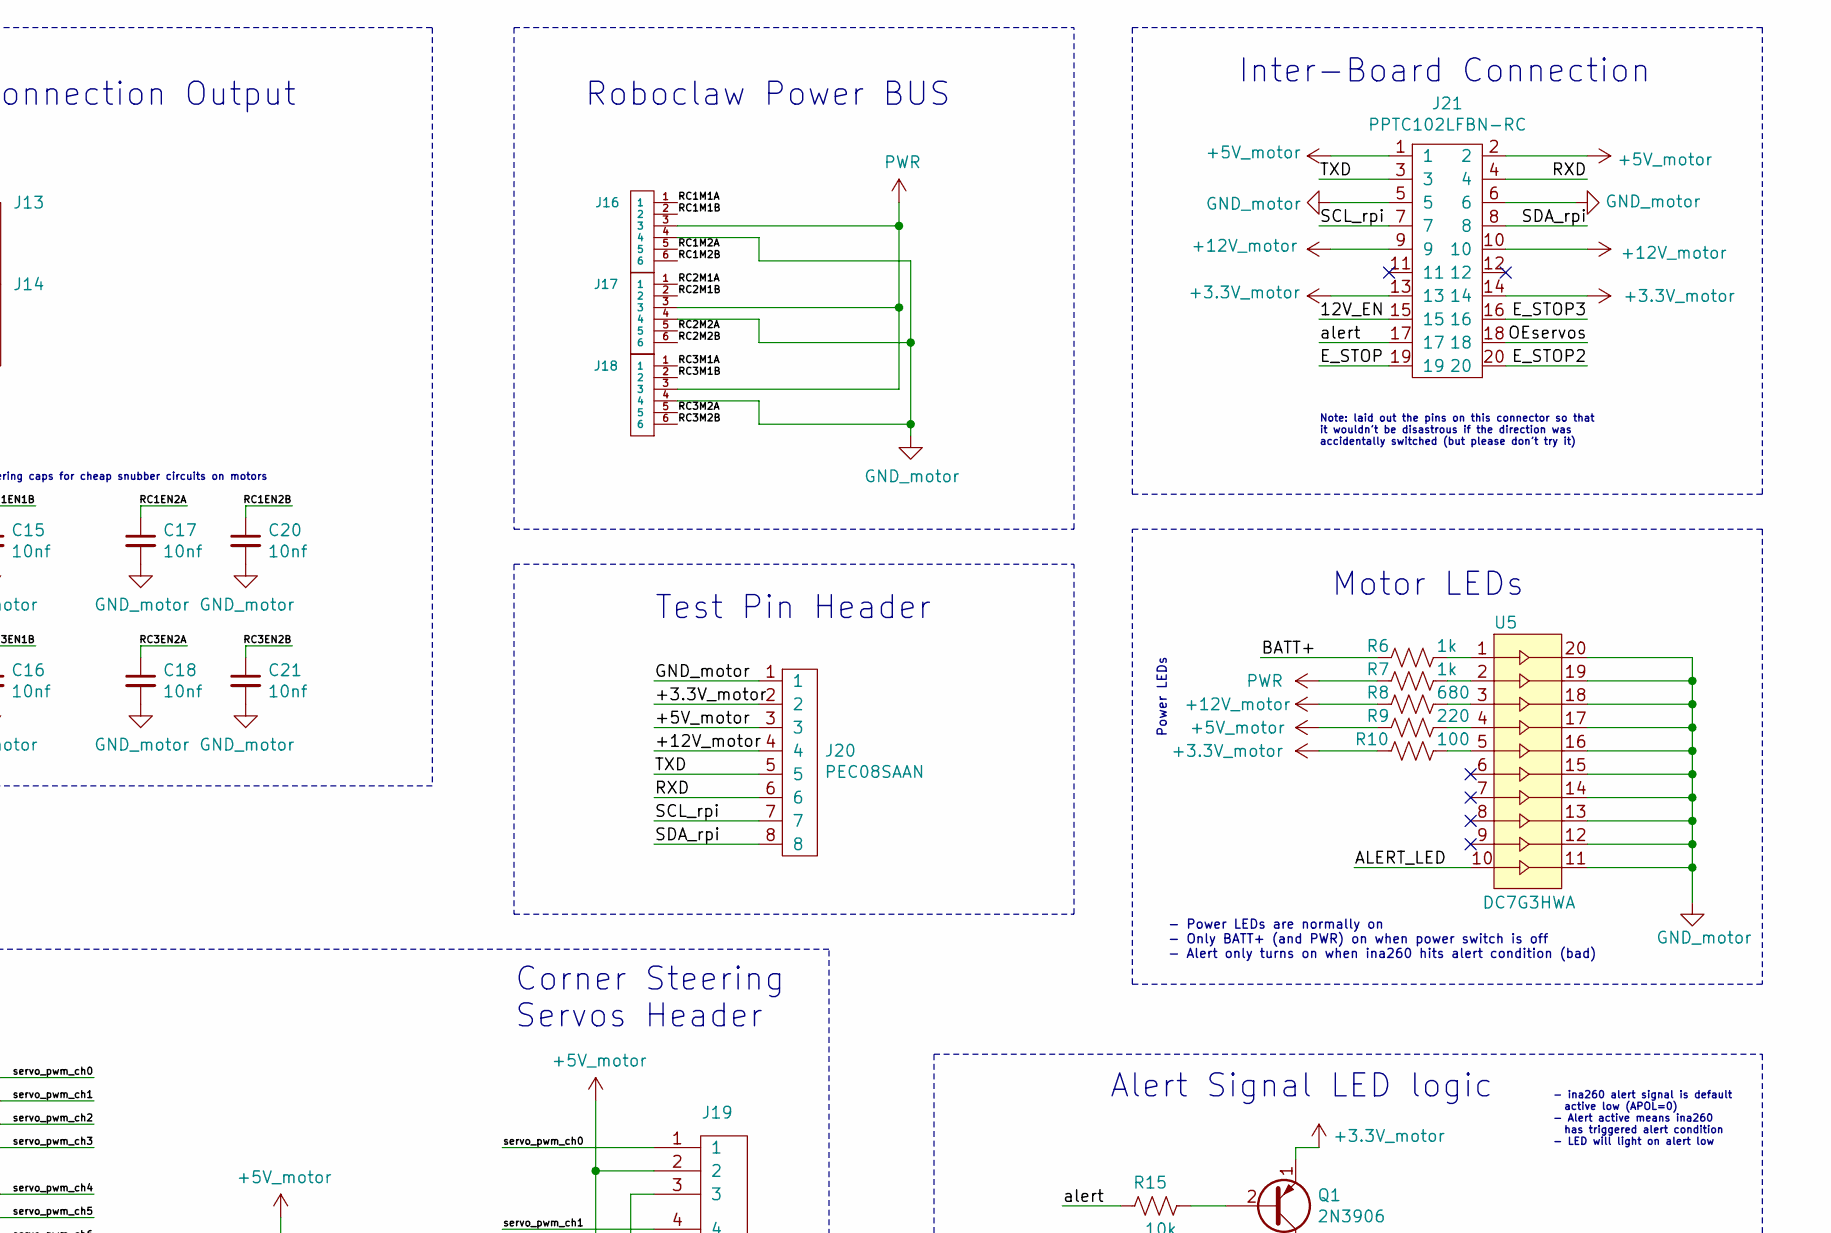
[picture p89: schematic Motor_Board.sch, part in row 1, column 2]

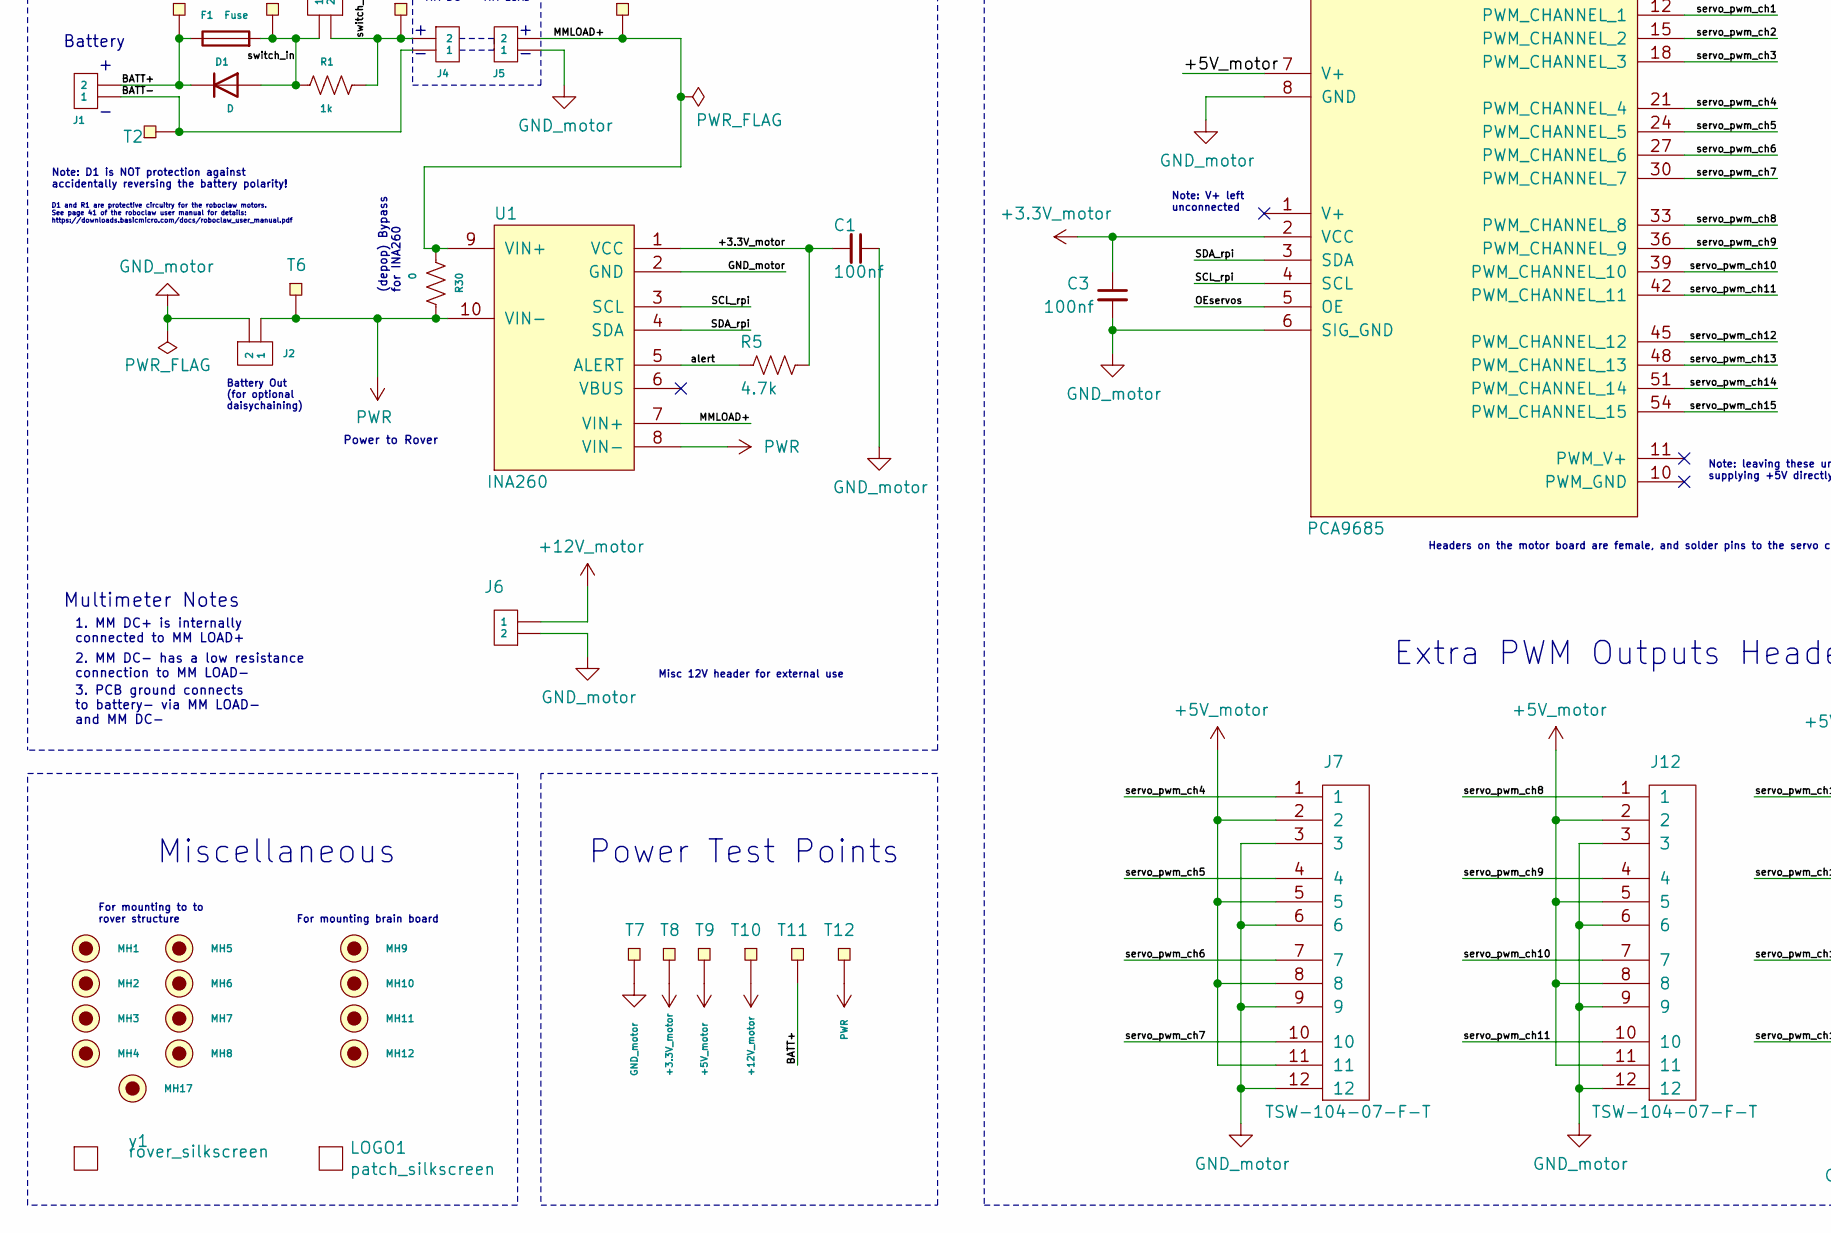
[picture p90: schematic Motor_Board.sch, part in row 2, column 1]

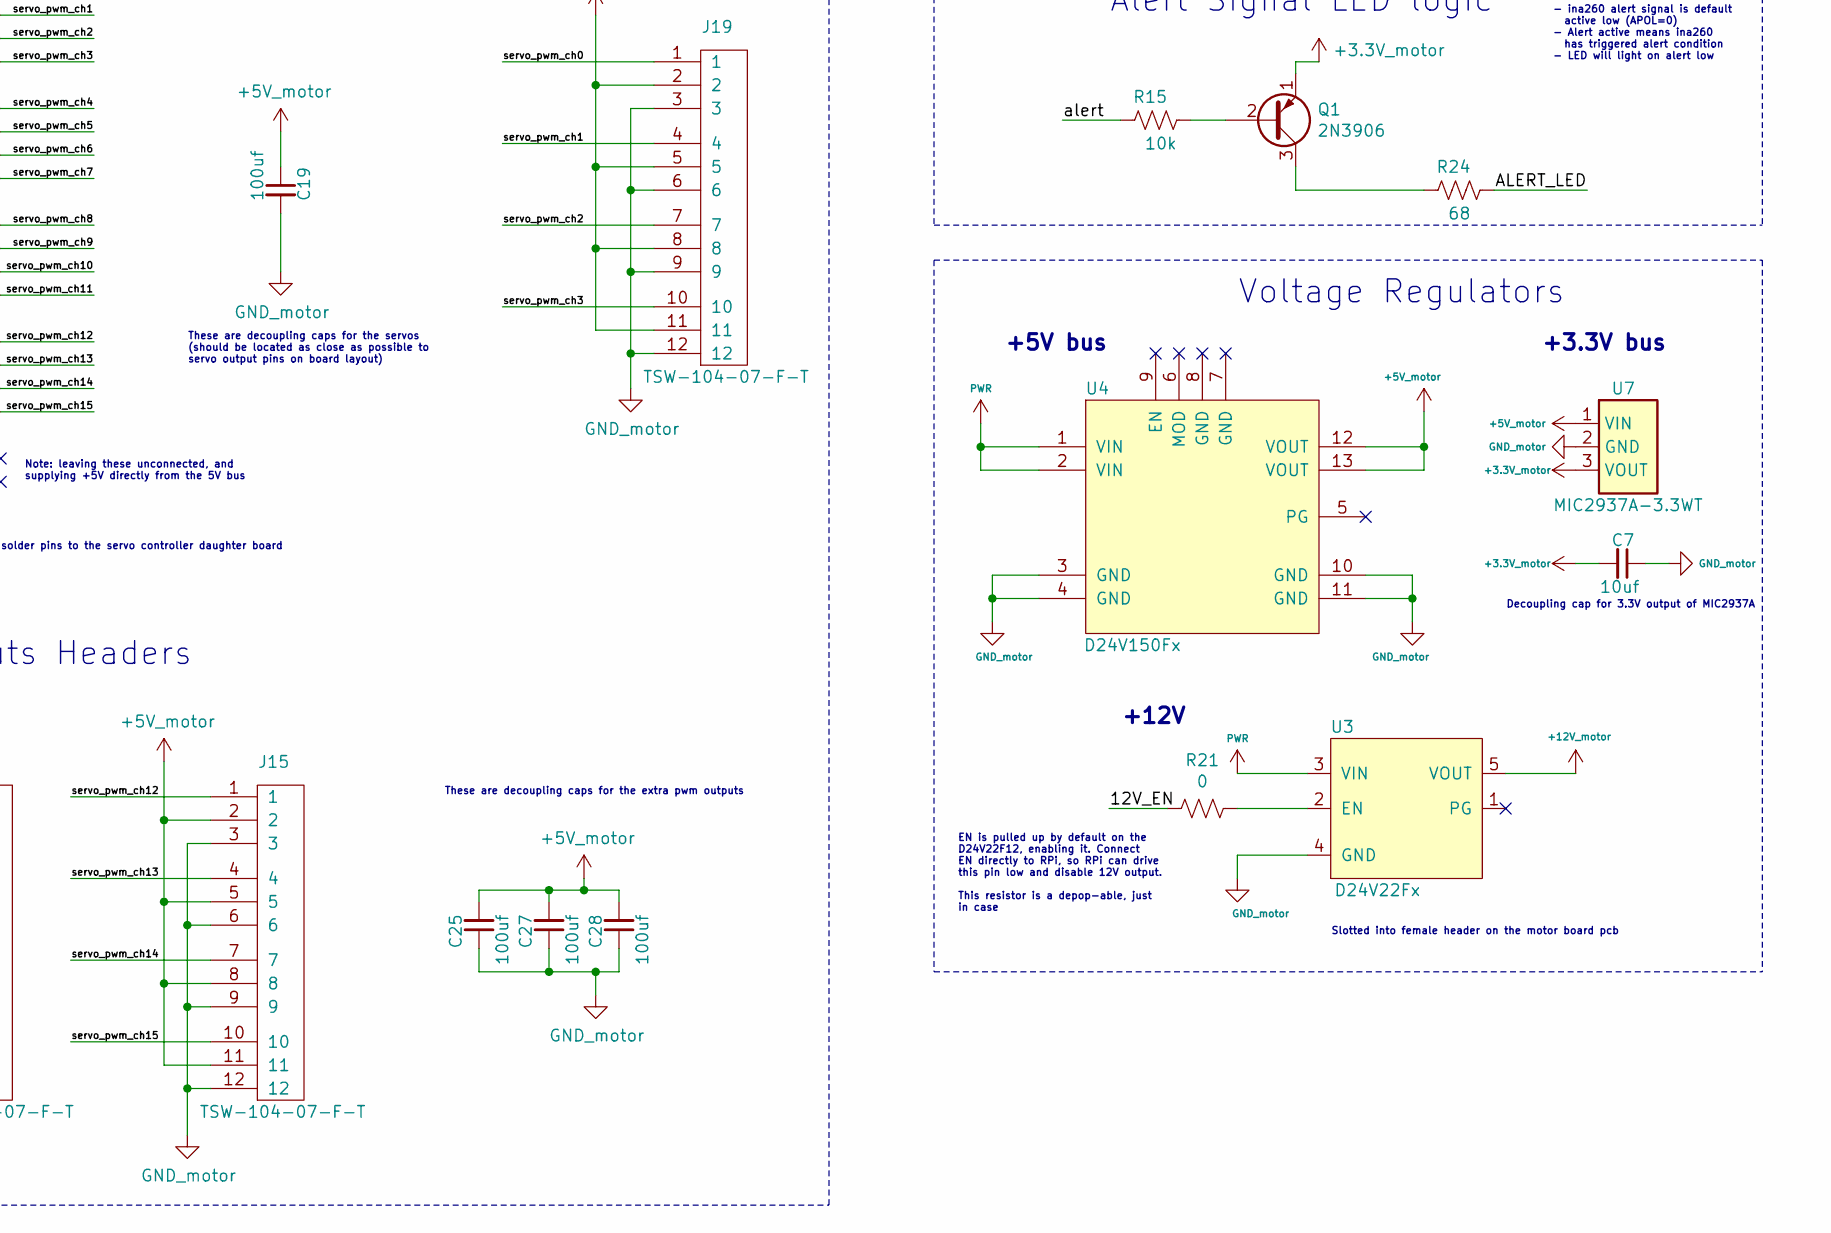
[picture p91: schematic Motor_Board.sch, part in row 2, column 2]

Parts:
C1, C3, C5, C6: 100nf; R_Axial_DIN0207_L6.3mm_D2.5mm_P7.62mm_Horizontal
C2, C4, C9, C10, C13, C14, C15, C16, C17, C18, C20, C21: 10nf; R_Axial_DIN0207_L6.3mm_D2.5mm_P7.62mm_Horizontal
C7: 10uf; CP_Radial_D8.0mm_P3.80mm
C19, C25, C27, C28: 100uf; CP_Radial_D8.0mm_P3.80mm
D1: D; 497-2738-5-ND
F1: Fuse; 696108003002_5x20_fuseholder
J1, J5: XT30-M; AMASS_XT30U-M_1x02_P5.0mm_Vertical
J2, J6: ED2580-ND
J3, J4: XT30-F; AMASS_XT30U-F_1x02_P5.0mm_Vertical
J7, J12, J15, J19: TSW-104-07-F-T; SSW-104-01-F-T
J8, J9, J10, J11, J13, J14: Molex_172675-0613
J16, J17, J18: 277-11404-ND
J20: PEC08SAAN; PinHeader_1x08_P2.54mm_Vertical
J21: PPTC102LFBN-RC
LOGO1: patch_silkscreen; patch_logo_scaled
MH1, MH2, MH3, MH4, MH5, MH6, MH7, MH8, MH17: #4THRU-HOLE
MH9, MH10, MH11, MH12: brain_board_mounting_hole
Q1: 2N3906; TO-92_Inline_Wide
R1, R6, R7: 1k; R_Axial_DIN0207_L6.3mm_D2.5mm_P7.62mm_Horizontal
R2, R3, R4, R5, R12, R13, R14: 4.7k; R_Axial_DIN0207_L6.3mm_D2.5mm_P7.62mm_Horizontal
R8: 680; R_Axial_DIN0207_L6.3mm_D2.5mm_P7.62mm_Horizontal
R9: 220; R_Axial_DIN0207_L6.3mm_D2.5mm_P7.62mm_Horizontal
R10: 100; R_Axial_DIN0207_L6.3mm_D2.5mm_P7.62mm_Horizontal
R15: 10k; R_Axial_DIN0207_L6.3mm_D2.5mm_P7.62mm_Horizontal
R21, R30: 0; R_Axial_DIN0207_L6.3mm_D2.5mm_P7.62mm_Horizontal
R24: 68; R_Axial_DIN0207_L6.3mm_D2.5mm_P7.62mm_Horizontal
RC1, RC2, RC3: RoboClaw; roboclaw_mount
T1, T2, T3, T4, T5, T6: test_point
T7, T8, T9, T10, T11, T12: test_point; test_point_hole
U1: INA260
U2: PCA9685; PCA9685_servo_controller
U3: D24V22Fx; D24V22Fx_regulator
U4: D24V150Fx
U5: DC7G3HWA; DC7G3HWA_led_array
U7: MIC2937A-3.3WT; TO-220-3_Vertical
y1: rover_silkscreen; rover_image

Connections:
+3.3V_motor: C1.2, C3.1, C7.2, J20.2, J21.13, J21.14, Q1.1 (E), R2.2, R3.2, R4.2, R5.1, R10.2, T8.1, U1.1 (VCC), U2.2 (VCC), U7.3 (VOUT)
+5V_motor: C5.1, C6.1, C19.1, C25.2, C27.2, C28.2, J7.2, J7.5, J7.8, J7.11, J8.4, J9.4, J10.4, J11.4, J12.2, J12.5, J12.8, J12.11, J13.4, J14.4, J15.2, J15.5, J15.8, J15.11, J19.2, J19.5, J19.8, J19.11, J20.3, J21.1, J21.2, R9.2, T9.1, U2.7 (V+), U4.12 (VOUT), U4.13 (VOUT), U7.1 (VIN)
+12V_motor: J6.1, J20.4, J21.9, J21.10, R8.2, T10.1, U3.5 (VOUT)
/Motor Board/12V_EN: J21.15, R21.2
/Motor Board/ALERT_LED: R24.1, U5.10
/Motor Board/BATT+: D1.1 (K), F1.1, J1.2, R6.2, T1.1, T11.1
/Motor Board/BATT-: J1.1, J4.1, T2.1
/Motor Board/E_STOP: J21.19, R2.1, R12.1, RC1.23 (S3I/O), RC2.23 (S3I/O), RC3.23 (S3I/O)
/Motor Board/E_STOP2: J21.20, R3.1, R13.1, RC1.24 (S4I/O), RC2.24 (S4I/O), RC3.24 (S4I/O)
/Motor Board/E_STOP3: J21.16, R4.1, R14.1, RC1.25 (S5I/O), RC2.25 (S5I/O), RC3.25 (S5I/O)
/Motor Board/MMLOAD+: J5.2, R30.2, T5.1, U1.7 (VIN+), U1.9 (VIN+)
/Motor Board/OEservos: J21.18, U2.5 (OE)
/Motor Board/RC1EN1A: C13.1, J8.5, RC1.7 (EN1A)
/Motor Board/RC1EN1B: C15.1, J8.6, RC1.8 (EN1B)
/Motor Board/RC1EN2A: C17.1, J9.5, RC1.9 (EN2A)
/Motor Board/RC1EN2B: C20.1, J9.6, RC1.10 (EN2B)
/Motor Board/RC1M1A: J8.1, J16.1
/Motor Board/RC1M1B: J8.2, J16.2
/Motor Board/RC1M2A: J9.1, J16.5
/Motor Board/RC1M2B: J9.2, J16.6
/Motor Board/RC2EN1A: C2.1, J10.5, RC2.7 (EN1A)
/Motor Board/RC2EN1B: C4.1, J10.6, RC2.8 (EN1B)
/Motor Board/RC2EN2A: C9.1, J11.5, RC2.9 (EN2A)
/Motor Board/RC2EN2B: C10.1, J11.6, RC2.10 (EN2B)
/Motor Board/RC2M1A: J10.1, J17.1
/Motor Board/RC2M1B: J10.2, J17.2
/Motor Board/RC2M2A: J11.1, J17.5
/Motor Board/RC2M2B: J11.2, J17.6
/Motor Board/RC3EN1A: C14.1, J13.5, RC3.7 (EN1A)
/Motor Board/RC3EN1B: C16.1, J13.6, RC3.8 (EN1B)
/Motor Board/RC3EN2A: C18.1, J14.5, RC3.9 (EN2A)
/Motor Board/RC3EN2B: C21.1, J14.6, RC3.10 (EN2B)
/Motor Board/RC3M1A: J13.1, J18.1
/Motor Board/RC3M1B: J13.2, J18.2
/Motor Board/RC3M2A: J14.1, J18.5
/Motor Board/RC3M2B: J14.2, J18.6
/Motor Board/RXD: J20.6, J21.4, RC1.22 (S2I/0), RC2.22 (S2I/0), RC3.22 (S2I/0)
/Motor Board/SCL_rpi: J20.7, J21.7, U1.3 (SCL), U2.4 (SCL)
/Motor Board/SDA_rpi: J20.8, J21.8, U1.4 (SDA), U2.3 (SDA)
/Motor Board/TXD: J20.5, J21.3, RC1.21 (S1I/O), RC2.21 (S1I/O), RC3.21 (S1I/O)
/Motor Board/alert: J21.17, R5.2, R15.2, U1.5 (ALERT)
/Motor Board/servo_pwm_ch0: J19.1, U2.9 (PWM_CHANNEL_0)
/Motor Board/servo_pwm_ch1: J19.4, U2.12 (PWM_CHANNEL_1)
/Motor Board/servo_pwm_ch2: J19.7, U2.15 (PWM_CHANNEL_2)
/Motor Board/servo_pwm_ch3: J19.10, U2.18 (PWM_CHANNEL_3)
/Motor Board/servo_pwm_ch4: J7.1, U2.21 (PWM_CHANNEL_4)
/Motor Board/servo_pwm_ch5: J7.4, U2.24 (PWM_CHANNEL_5)
/Motor Board/servo_pwm_ch6: J7.7, U2.27 (PWM_CHANNEL_6)
/Motor Board/servo_pwm_ch7: J7.10, U2.30 (PWM_CHANNEL_7)
/Motor Board/servo_pwm_ch8: J12.1, U2.33 (PWM_CHANNEL_8)
/Motor Board/servo_pwm_ch9: J12.4, U2.36 (PWM_CHANNEL_9)
/Motor Board/servo_pwm_ch10: J12.7, U2.39 (PWM_CHANNEL_10)
/Motor Board/servo_pwm_ch11: J12.10, U2.42 (PWM_CHANNEL_11)
/Motor Board/servo_pwm_ch12: J15.1, U2.45 (PWM_CHANNEL_12)
/Motor Board/servo_pwm_ch13: J15.4, U2.48 (PWM_CHANNEL_13)
/Motor Board/servo_pwm_ch14: J15.7, U2.51 (PWM_CHANNEL_14)
/Motor Board/servo_pwm_ch15: J15.10, U2.54 (PWM_CHANNEL_15)
/Motor Board/switch_in: D1.2 (A), F1.2, J3.1, R1.2, T3.1
/Motor Board/switch_out: J3.2, J4.2, R1.1, T4.1
GND_motor: C1.1, C2.2, C3.2, C4.2, C5.2, C6.2, C7.1, C9.2, C10.2, C13.2, C14.2, C15.2, C16.2, C17.2, C18.2, C19.2, C20.2, C21.2, C25.1, C27.1, C28.1, J2.2, J5.1, J6.2, J7.3, J7.6, J7.9, J7.12, J8.3, J9.3, J10.3, J11.3, J12.3, J12.6, J12.9, J12.12, J13.3, J14.3, J15.3, J15.6, J15.9, J15.12, J16.4, J17.4, J18.4, J19.3, J19.6, J19.9, J19.12, J20.1, J21.5, J21.6, R12.2, R13.2, R14.2, T7.1, U1.2 (GND), U2.6 (SIG_GND), U2.8 (GND), U3.4 (GND), U4.3 (GND), U4.4 (GND), U4.10 (GND), U4.11 (GND), U5.11, U5.12, U5.13, U5.14, U5.15, U5.16, U5.17, U5.18, U5.19, U5.20, U7.2 (GND)
unnamed: Q1.2 (B), R15.1
unnamed: Q1.3 (C), R24.2
unnamed: R6.1, U5.1
unnamed: R7.1, U5.2
unnamed: R8.1, U5.3
unnamed: R9.1, U5.4
unnamed: R10.1, U5.5
unnamed: R21.1, U3.2 (EN)
PWR: J2.1, J16.3, J17.3, J18.3, R7.2, R30.1, T6.1, T12.1, U1.8 (VIN-), U1.10 (VIN-), U3.3 (VIN), U4.1 (VIN), U4.2 (VIN)

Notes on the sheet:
RoboClaw Pin Header
Roboclaw Power BUS
Roboclaw Motor Connection Output
Voltage Regulators
Power Distribution
Battery
Multimeter Notes
1. MM DC+ is internally connected to MM LOAD+
Inter-Board Connection
Option 1: Pulllups for e_stop signals Populate to NOT e-stop by default
Test Pin Header
Note: V+ left unconnected
Motor LEDs
Filtering caps for cheap snubber circuits on motors
Note: leaving these unconnected, and supplying +5V directly from the 5V bus
Misc 12V header for external use
Headers on the motor board are female, and solder pins to the servo controller daughter board
These are decoupling caps for the servos (should be located as close as possible to servo output pins on board layout)
EN is pulled up by default on the D24V22F12, enabling it. Connect EN directly to RPi, so RPi can drive this pin low and disable 12V output. This resistor is a depop-able, just in case
Note: laid out the pins on this connector so that it wouldn’t be disastrous if the direction was accidentally switched (but please don’t try it)
Switch
Battery Out (for optional daisychaining)
MM LOAD
MM DC
Remeber this fuse goes with PN: 507-2121-ND
2. MM DC- has a low resistance connection to MM LOAD-
Multimeter
Power to Rover
For mounting to to rover structure
For mounting brain board
Corner Steering Servos Header
Extra PWM Outputs Headers
Power Test Points
Miscellaneous
3. PCB ground connects to battery- via MM LOAD- and MM DC-
(depop) Bypass for INA260
Alert Signal LED logic
- ina260 alert signal is default active low (APOL=0) - Alert active means ina260 has triggered alert condition - LED will light on alert low
Option 2: Pullldowns for e_stop signals Populate to e-stop by default (don’t populate at same time as Option 1!)
+5V bus

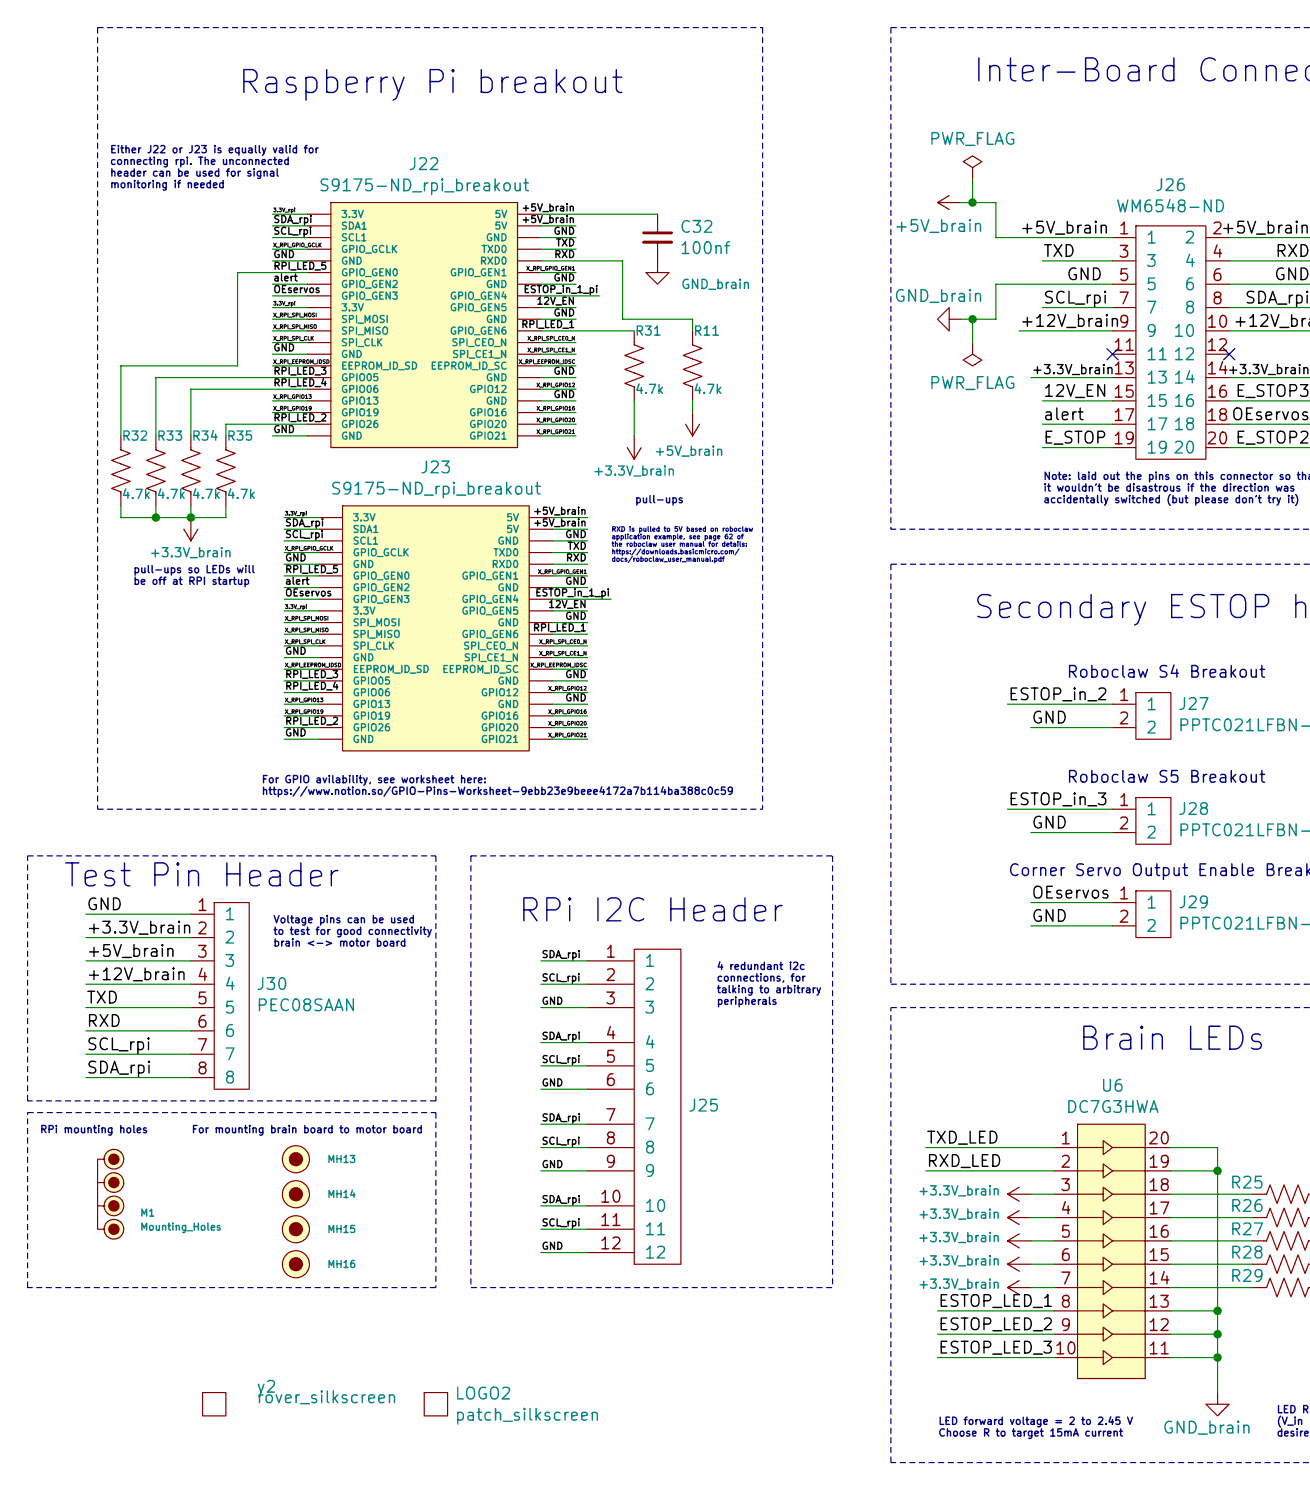
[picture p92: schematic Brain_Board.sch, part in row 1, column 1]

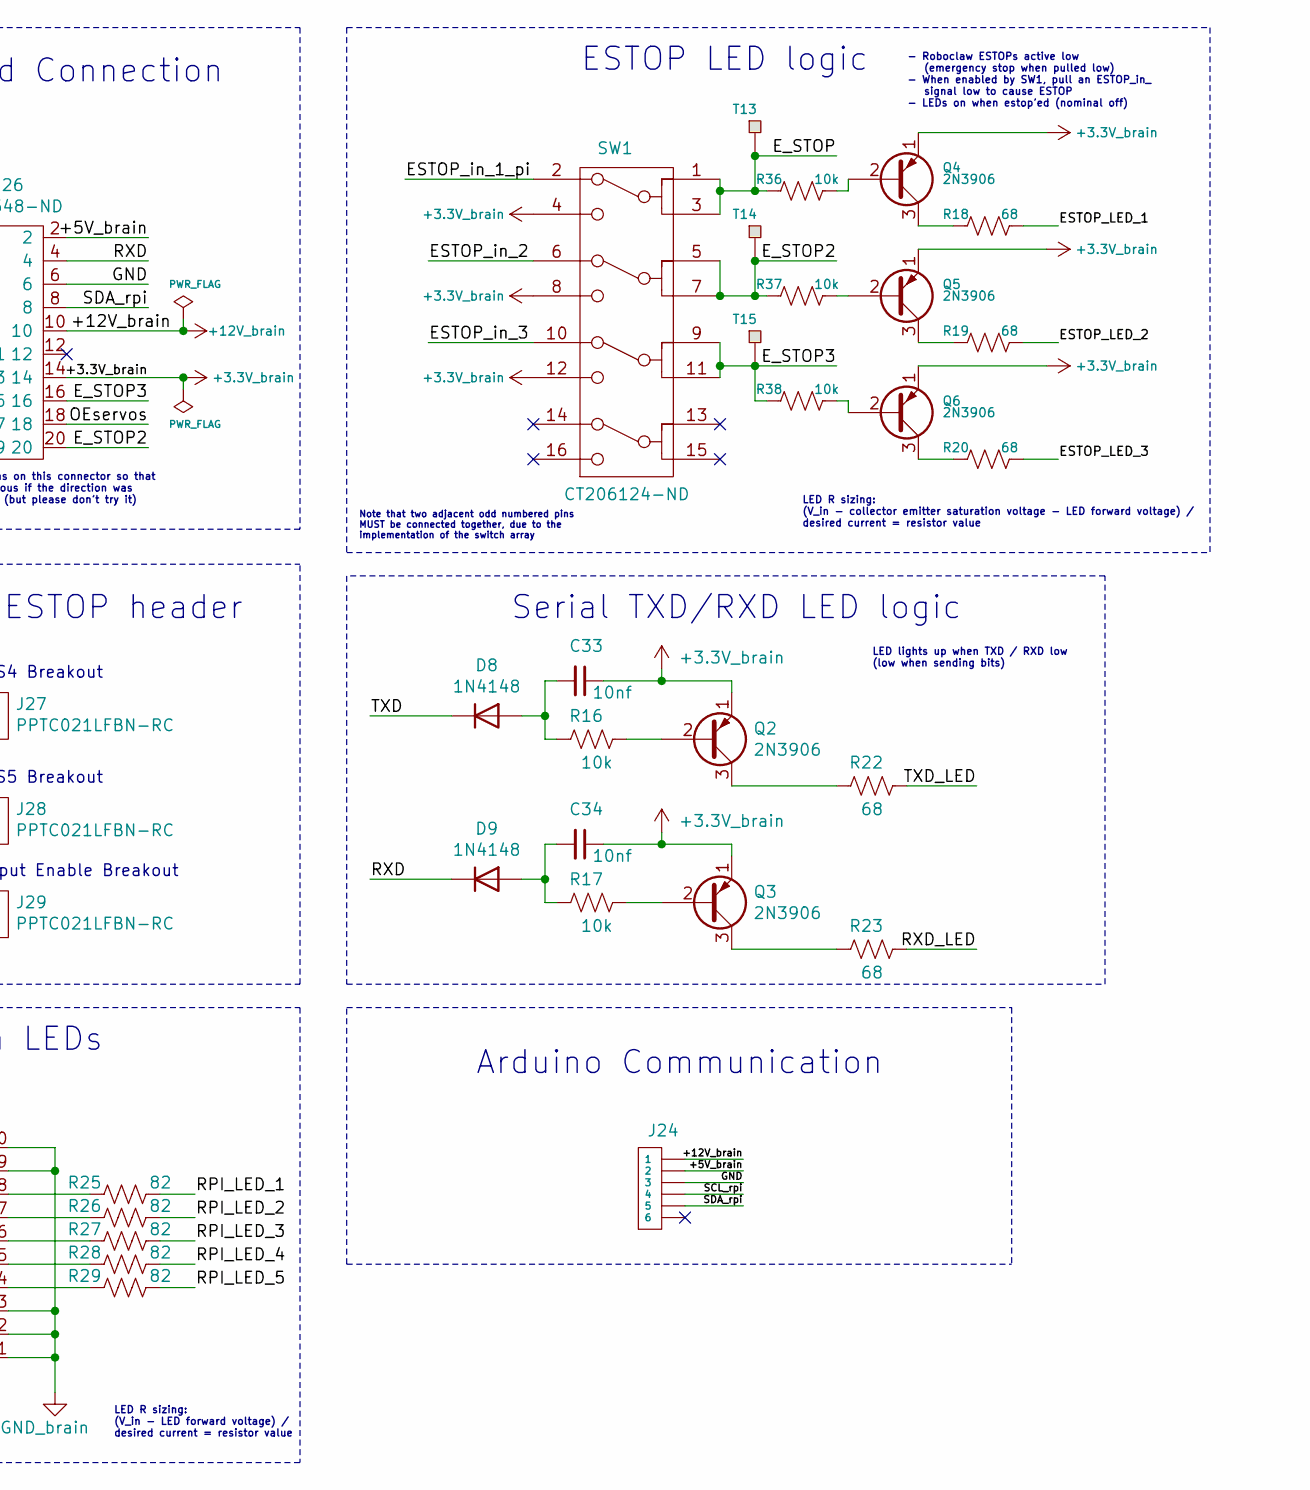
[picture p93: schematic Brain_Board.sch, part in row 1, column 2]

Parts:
C32: 100nf; R_Axial_DIN0207_L6.3mm_D2.5mm_P7.62mm_Horizontal
C33, C34: 10nf; R_Axial_DIN0207_L6.3mm_D2.5mm_P7.62mm_Horizontal
D8, D9: 1N4148; D_DO-35_SOD27_P7.62mm_Horizontal
J22, J23: S9175-ND_rpi_breakout; S9175-ND
J24: 6posheader; 455-1708-ND
J25: SSW-104-01-F-T
J26: WM6548-ND
J27, J28, J29: PPTC021LFBN-RC
J30: PEC08SAAN; PinHeader_1x08_P2.54mm_Vertical
LOGO2: patch_silkscreen; patch_logo_scaled
M1: Mounting_Holes; raspberry_pi_3b
MH13, MH14, MH15, MH16: brain_board_mounting_hole
Q2, Q3, Q4, Q5, Q6: 2N3906; TO-92_Inline_Wide
R11, R31, R32, R33, R34, R35: 4.7k; R_Axial_DIN0207_L6.3mm_D2.5mm_P7.62mm_Horizontal
R16, R17, R36, R37, R38: 10k; R_Axial_DIN0207_L6.3mm_D2.5mm_P7.62mm_Horizontal
R18, R19, R20, R22, R23: 68; R_Axial_DIN0207_L6.3mm_D2.5mm_P7.62mm_Horizontal
R25, R26, R27, R28, R29: 82; R_Axial_DIN0207_L6.3mm_D2.5mm_P7.62mm_Horizontal
SW1: CT206124-ND; CTS-206-124
T13, T14, T15: test_point
U6: DC7G3HWA; DC7G3HWA_led_array
y2: rover_silkscreen; rover_image

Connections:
+3.3V_brain: C33.1, C34.1, J26.13, J26.14, J30.2, Q2.1 (E), Q3.1 (E), Q4.1 (E), Q5.1 (E), Q6.1 (E), R31.2, R32.2, R33.2, R34.2, R35.2, SW1.4 (out1_2), SW1.8 (out2_2), SW1.12 (out3_2), U6.3, U6.4, U6.5, U6.6, U6.7
+5V_brain: C32.1, J22.2 (5V), J22.4 (5V), J23.2 (5V), J23.4 (5V), J24.2, J26.1, J26.2, J30.3, R11.2
+12V_brain: J24.1, J26.9, J26.10, J30.4
/Brain Board/3.3V_rpi: J22.1 (3.3V), J22.17 (3.3V), J23.1 (3.3V), J23.17 (3.3V)
/Brain Board/12V_EN: J22.18 (GPIO_GEN5), J23.18 (GPIO_GEN5), J26.15
/Brain Board/ESTOP_LED_1: R18.1, U6.8
/Brain Board/ESTOP_LED_2: R19.1, U6.9
/Brain Board/ESTOP_LED_3: R20.1, U6.10
/Brain Board/ESTOP_in_1_pi: J22.16 (GPIO_GEN4), J23.16 (GPIO_GEN4), SW1.2 (out1_1)
/Brain Board/ESTOP_in_2: J27.1, SW1.6 (out2_1)
/Brain Board/ESTOP_in_3: J28.1, SW1.10 (out3_1)
/Brain Board/E_STOP: J26.19, R36.2, SW1.1 (in1_1), SW1.3 (in1_2), T13.1
/Brain Board/E_STOP2: J26.20, R37.2, SW1.5 (in2_1), SW1.7 (in2_2), T14.1
/Brain Board/E_STOP3: J26.16, R38.2, SW1.9 (in3_1), SW1.11 (in3_2), T15.1
/Brain Board/OEservos: J22.15 (GPIO_GEN3), J23.15 (GPIO_GEN3), J26.18, J29.1
/Brain Board/RPI_LED_1: J22.22 (GPIO_GEN6), J23.22 (GPIO_GEN6), R25.1, R31.1
/Brain Board/RPI_LED_2: J22.37 (GPIO26), J23.37 (GPIO26), R26.1, R35.1
/Brain Board/RPI_LED_3: J22.29 (GPIO05), J23.29 (GPIO05), R27.1, R33.1
/Brain Board/RPI_LED_4: J22.31 (GPIO06), J23.31 (GPIO06), R28.1, R34.1
/Brain Board/RPI_LED_5: J22.11 (GPIO_GEN0), J23.11 (GPIO_GEN0), R29.1, R32.1
/Brain Board/RXD: D9.1 (K), J22.10 (RXD0), J23.10 (RXD0), J26.4, J30.6, R11.1
/Brain Board/RXD_LED: R23.1, U6.2
/Brain Board/SCL_rpi: J22.5 (SCL1), J23.5 (SCL1), J24.4, J25.2, J25.5, J25.8, J25.11, J26.7, J30.7
/Brain Board/SDA_rpi: J22.3 (SDA1), J23.3 (SDA1), J24.5, J25.1, J25.4, J25.7, J25.10, J26.8, J30.8
/Brain Board/TXD: D8.1 (K), J22.8 (TXD0), J23.8 (TXD0), J26.3, J30.5
/Brain Board/TXD_LED: R22.1, U6.1
/Brain Board/X_RPI_EEPROM_IDSC: J22.28 (EEPROM_ID_SC), J23.28 (EEPROM_ID_SC)
/Brain Board/X_RPI_EEPROM_IDSD: J22.27 (EEPROM_ID_SD), J23.27 (EEPROM_ID_SD)
/Brain Board/X_RPI_GPIO12: J22.32 (GPIO12), J23.32 (GPIO12)
/Brain Board/X_RPI_GPIO13: J22.33 (GPIO13), J23.33 (GPIO13)
/Brain Board/X_RPI_GPIO16: J22.36 (GPIO16), J23.36 (GPIO16)
/Brain Board/X_RPI_GPIO19: J22.35 (GPIO19), J23.35 (GPIO19)
/Brain Board/X_RPI_GPIO20: J22.38 (GPIO20), J23.38 (GPIO20)
/Brain Board/X_RPI_GPIO21: J22.40 (GPIO21), J23.40 (GPIO21)
/Brain Board/X_RPI_GPIO_GCLK: J22.7 (GPIO_GCLK), J23.7 (GPIO_GCLK)
/Brain Board/X_RPI_GPIO_GEN1: J22.12 (GPIO_GEN1), J23.12 (GPIO_GEN1)
/Brain Board/X_RPI_SPI_CE0_N: J22.24 (SPI_CEO_N), J23.24 (SPI_CEO_N)
/Brain Board/X_RPI_SPI_CE1_N: J22.26 (SPI_CE1_N), J23.26 (SPI_CE1_N)
/Brain Board/X_RPI_SPI_CLK: J22.23 (SPI_CLK), J23.23 (SPI_CLK)
/Brain Board/X_RPI_SPI_MISO: J22.21 (SPI_MISO), J23.21 (SPI_MISO)
/Brain Board/X_RPI_SPI_MOSI: J22.19 (SPI_MOSI), J23.19 (SPI_MOSI)
/Brain Board/alert: J22.13 (GPIO_GEN2), J23.13 (GPIO_GEN2), J26.17
GND_brain: C32.2, J22.6 (GND), J22.9 (GND), J22.14 (GND), J22.20 (GND), J22.25 (GND), J22.30 (GND), J22.34 (GND), J22.39 (GND), J23.6 (GND), J23.9 (GND), J23.14 (GND), J23.20 (GND), J23.25 (GND), J23.30 (GND), J23.34 (GND), J23.39 (GND), J24.3, J25.3, J25.6, J25.9, J25.12, J26.5, J26.6, J27.2, J28.2, J29.2, J30.1, U6.11, U6.12, U6.13, U6.19, U6.20
unnamed: C33.2, D8.2 (A), R16.2
unnamed: C34.2, D9.2 (A), R17.2
unnamed: Q2.2 (B), R16.1
unnamed: Q2.3 (C), R22.2
unnamed: Q3.2 (B), R17.1
unnamed: Q3.3 (C), R23.2
unnamed: Q4.2 (B), R36.1
unnamed: Q4.3 (C), R18.2
unnamed: Q5.2 (B), R37.1
unnamed: Q5.3 (C), R19.2
unnamed: Q6.2 (B), R38.1
unnamed: Q6.3 (C), R20.2
unnamed: R25.2, U6.18
unnamed: R26.2, U6.17
unnamed: R27.2, U6.16
unnamed: R28.2, U6.15
unnamed: R29.2, U6.14

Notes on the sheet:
Raspberry Pi breakout
Arduino Communication
Inter-Board Connection
Secondary ESTOP header
Roboclaw S4 Breakout
Roboclaw S5 Breakout
Corner Servo Output Enable Breakout
RPi I2C Header
ESTOP LED logic
LED lights up when TXD / RXD low (low when sending bits)
Serial TXD/RXD LED logic
- Roboclaw ESTOPs active low (emergency stop when pulled low) - When enabled by SW1, pull an ESTOP_in_ signal low to cause ESTOP - LEDs on when estop’ed (nominal off)
4 redundant i2c connections, for talking to arbitrary peripherals
Note that two adjacent odd numbered pins MUST be connected together, due to the implementation of the switch array
For mounting brain board to motor board
RPi mounting holes
Brain LEDs
For GPIO avilability, see worksheet here: https://www.notion.so/GPIO-Pins-Worksheet-9ebb23e9beee4172a7b114ba388c0c59
LED R sizing: (V_in - collector emitter saturation voltage - LED forward voltage) / desired current = resistor value
LED forward voltage = 2 to 2.45 V Choose R to target 15mA current
Test Pin Header
pull-ups
pull-ups so LEDs will be off at RPI startup
RXD is pulled to 5V based on roboclaw application example, see page 62 of the roboclaw user manual for details: https://downloads.basicmicro.com/ docs/roboclaw_user_manual.pdf
LED R sizing: (V_in - LED forward voltage) / desired current = resistor value
Either J22 or J23 is equally valid for connecting rpi. The unconnected header can be used for signal monitoring if needed
Voltage pins can be used to test for good connectivity brain <-> motor board
Note: laid out the pins on this connector so that it wouldn’t be disastrous if the direction was accidentally switched (but please don’t try it)

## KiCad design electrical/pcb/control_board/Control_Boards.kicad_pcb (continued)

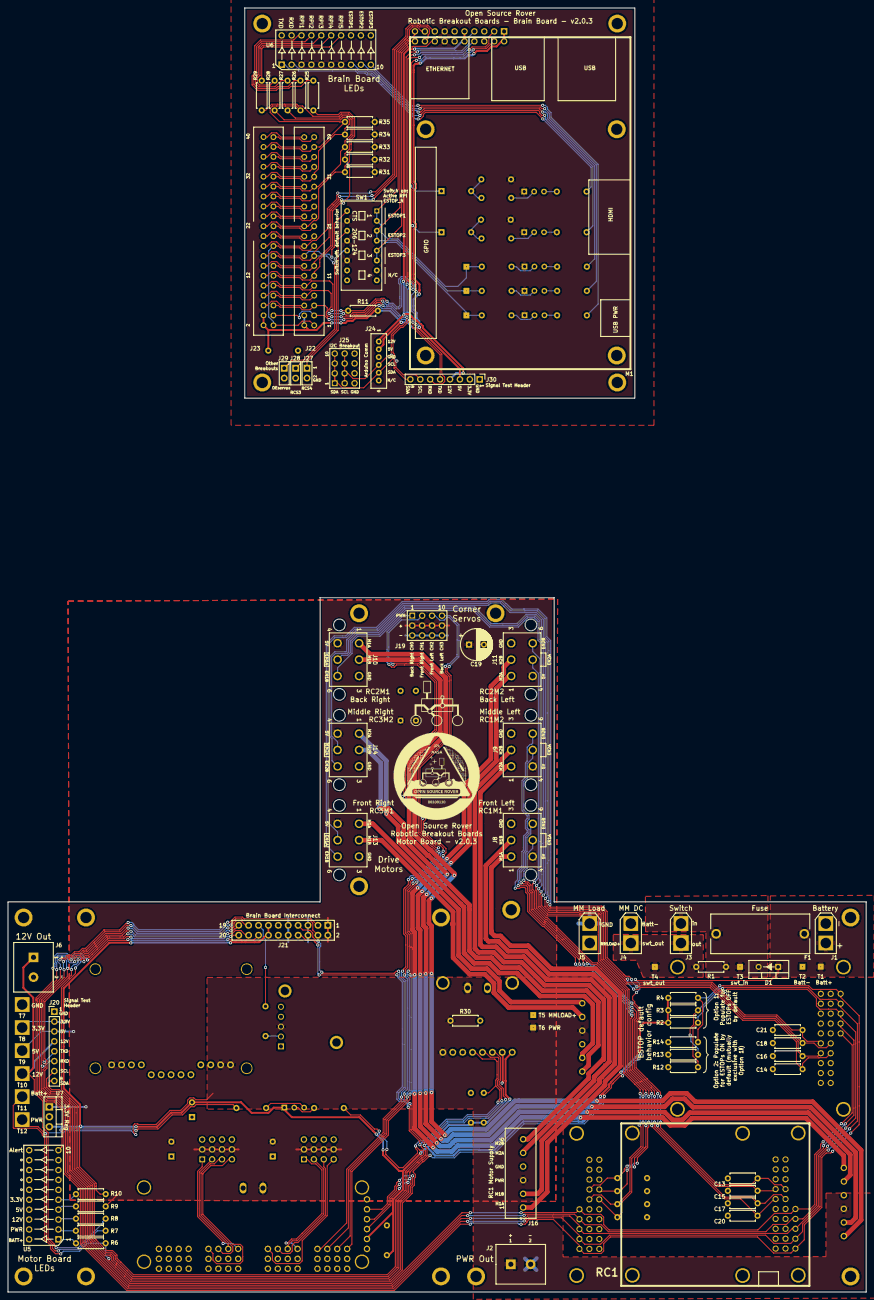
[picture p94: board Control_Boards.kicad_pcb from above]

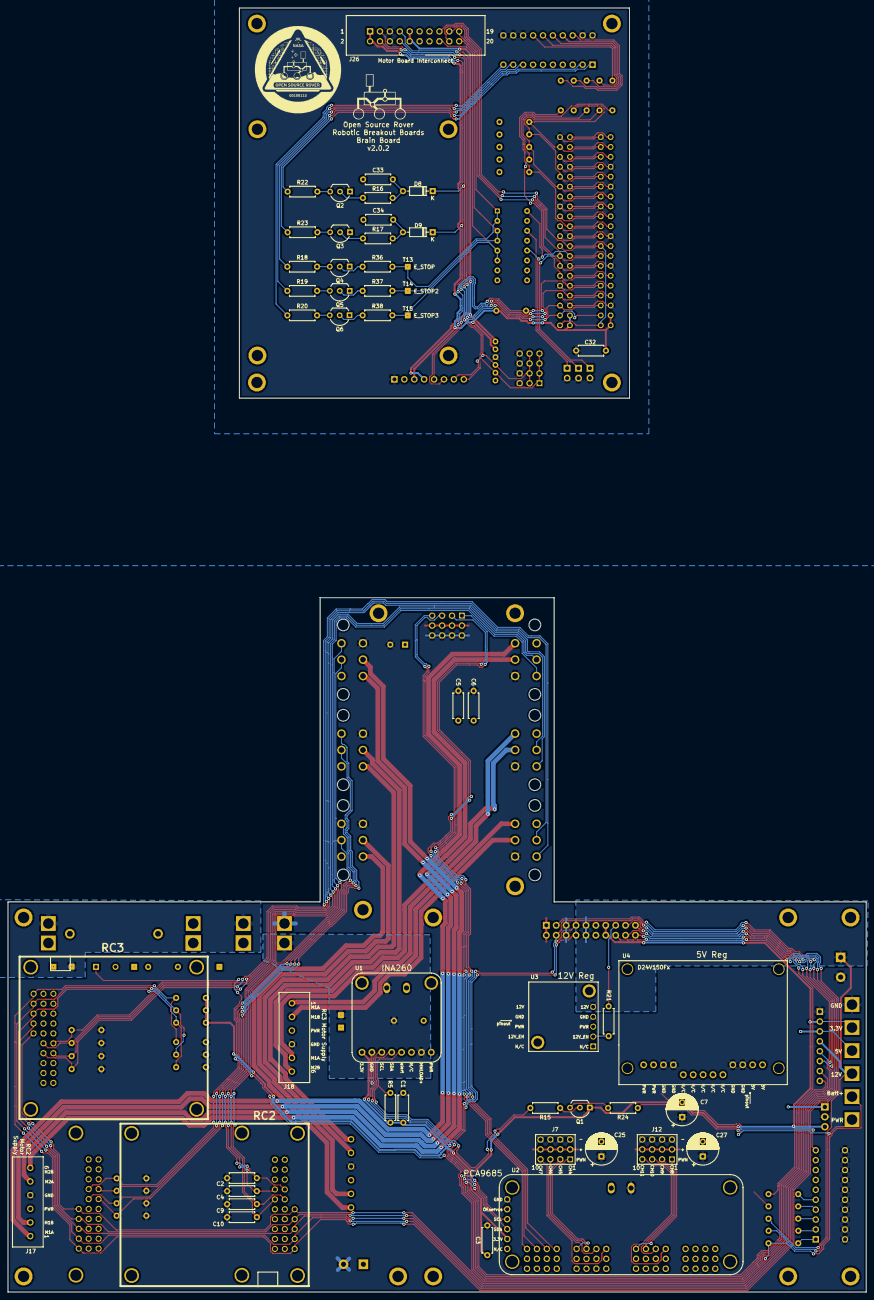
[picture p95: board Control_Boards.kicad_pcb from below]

Board: 2 copper layers, 220.0 x 329.2 mm, 148 parts (51 on the bottom side), 125 nets.

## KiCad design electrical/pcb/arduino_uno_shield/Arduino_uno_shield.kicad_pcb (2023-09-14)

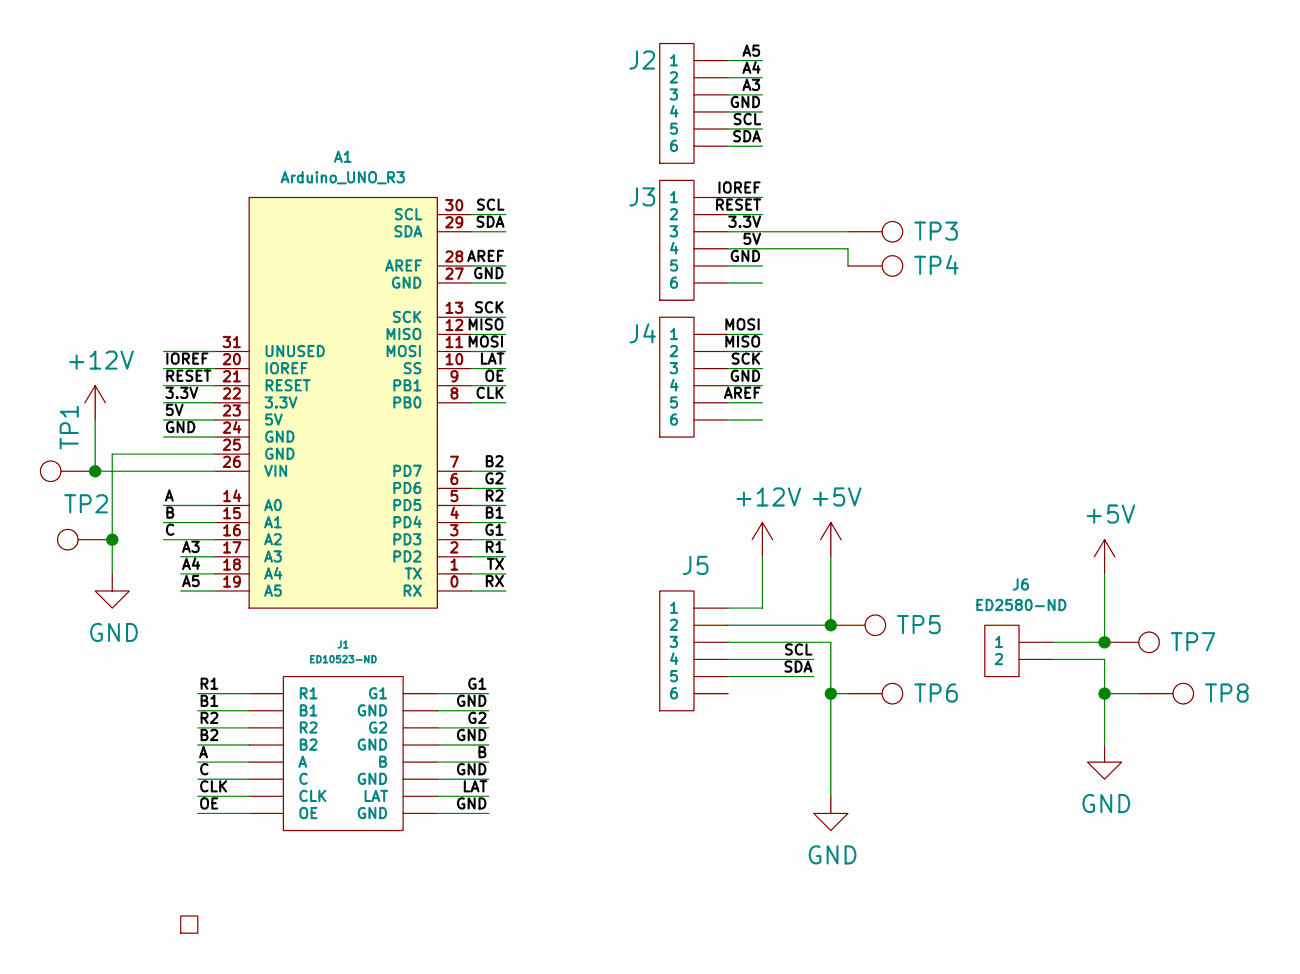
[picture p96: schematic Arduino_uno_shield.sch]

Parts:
A1: Arduino_UNO_R3; Arduino Uno Shield
J1: ED10523-ND; 16 pos 3M connector
J2, J3, J4: 6posheader; 6 pos header pin
J5: 6posheader; 455-1708-ND
J6: ED2580-ND; ED1501-ND
TP1, TP2, TP3, TP4, TP5, TP6, TP7, TP8: TestPoint; TestPoint_Pad_1.0x1.0mm
y1: rover_silkscreen; rover_image

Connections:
+5V: J5.2, J6.1, TP5.1, TP7.1
+12V: A1.26 (VIN), J5.1, TP1.1
/3.3V: A1.22 (3.3V), J3.3, TP3.1
/5V: A1.23 (5V), J3.4, TP4.1
/A: A1.14 (A0), J1.9 (A)
/A3: A1.17 (A3), J2.3
/A4: A1.18 (A4), J2.2
/A5: A1.19 (A5), J2.1
/AREF: A1.28 (AREF), J4.5
/B: A1.15 (A1), J1.10 (B)
/B1: A1.4 (PD4), J1.3 (B1)
/B2: A1.7 (PD7), J1.7 (B2)
/C: A1.16 (A2), J1.11 (C)
/CLK: A1.8 (PB0), J1.13 (CLK)
/G1: A1.3 (PD3), J1.2 (G1)
/G2: A1.6 (PD6), J1.6 (G2)
/IOREF: A1.20 (IOREF), J3.1
/LAT: A1.10 (SS), J1.14 (LAT)
/MISO: A1.12 (MISO), J4.2
/MOSI: A1.11 (MOSI), J4.1
/OE: A1.9 (PB1), J1.15 (OE)
/R1: A1.2 (PD2), J1.1 (R1)
/R2: A1.5 (PD5), J1.5 (R2)
/RESET: A1.21 (RESET), J3.2
/RX: A1.0 (RX)
/SCK: A1.13 (SCK), J4.3
/SCL: A1.30 (SCL), J2.5, J5.4
/SDA: A1.29 (SDA), J2.6, J5.5
/TX: A1.1 (TX)
GND: A1.24 (GND), A1.25 (GND), A1.27 (GND), J1.4 (GND), J1.8 (GND), J1.12 (GND), J1.16 (GND), J2.4, J3.5, J4.4, J5.3, J6.2, TP2.1, TP6.1, TP8.1

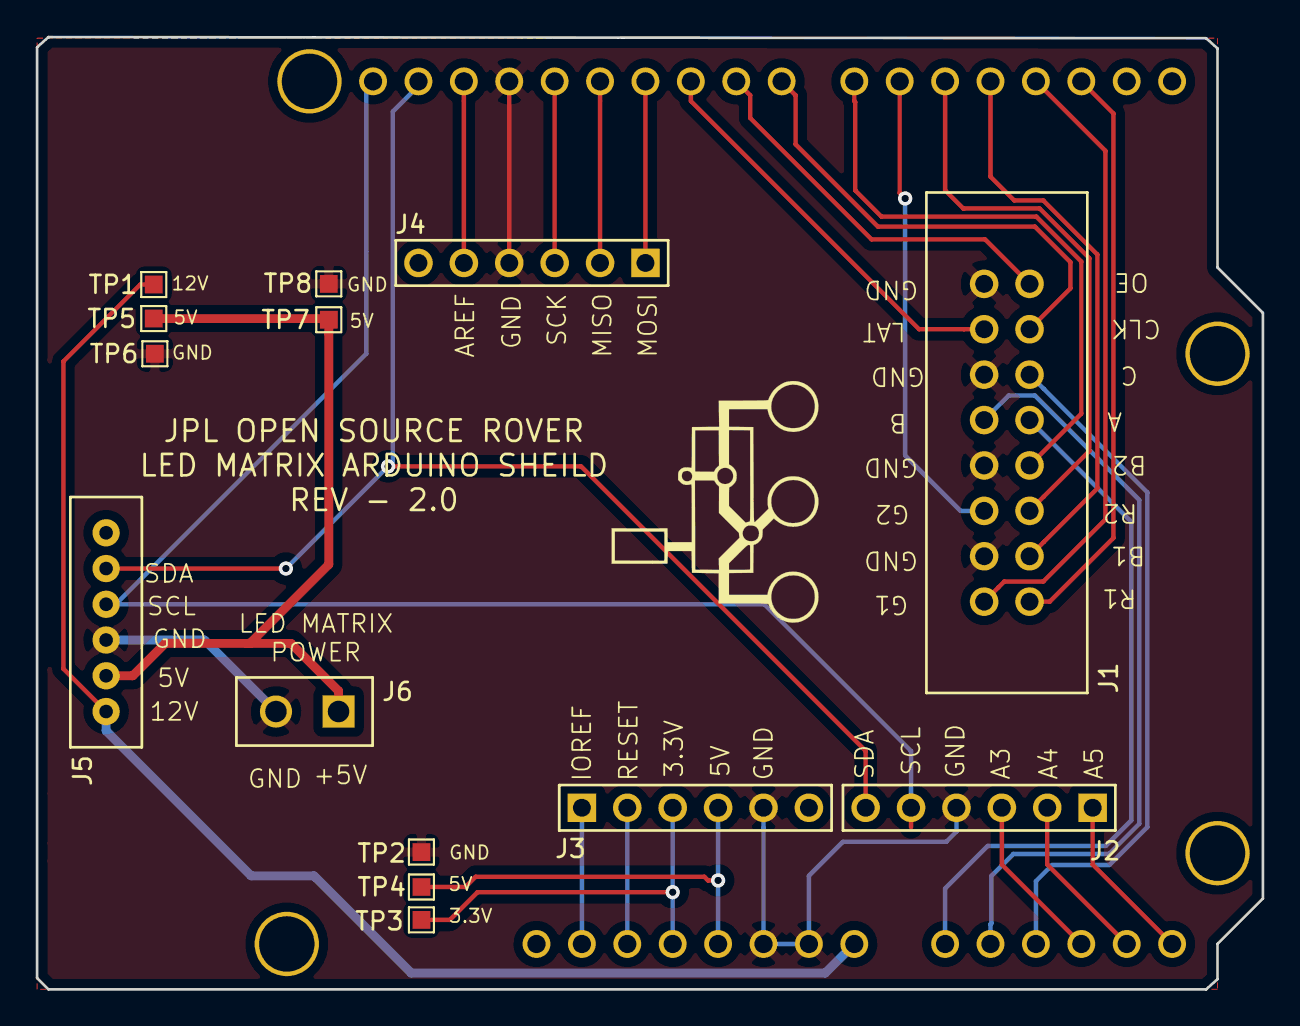
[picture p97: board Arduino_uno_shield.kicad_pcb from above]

Board: 2 copper layers, 68.6 x 53.3 mm, 16 parts (0 on the bottom side), 28 nets.

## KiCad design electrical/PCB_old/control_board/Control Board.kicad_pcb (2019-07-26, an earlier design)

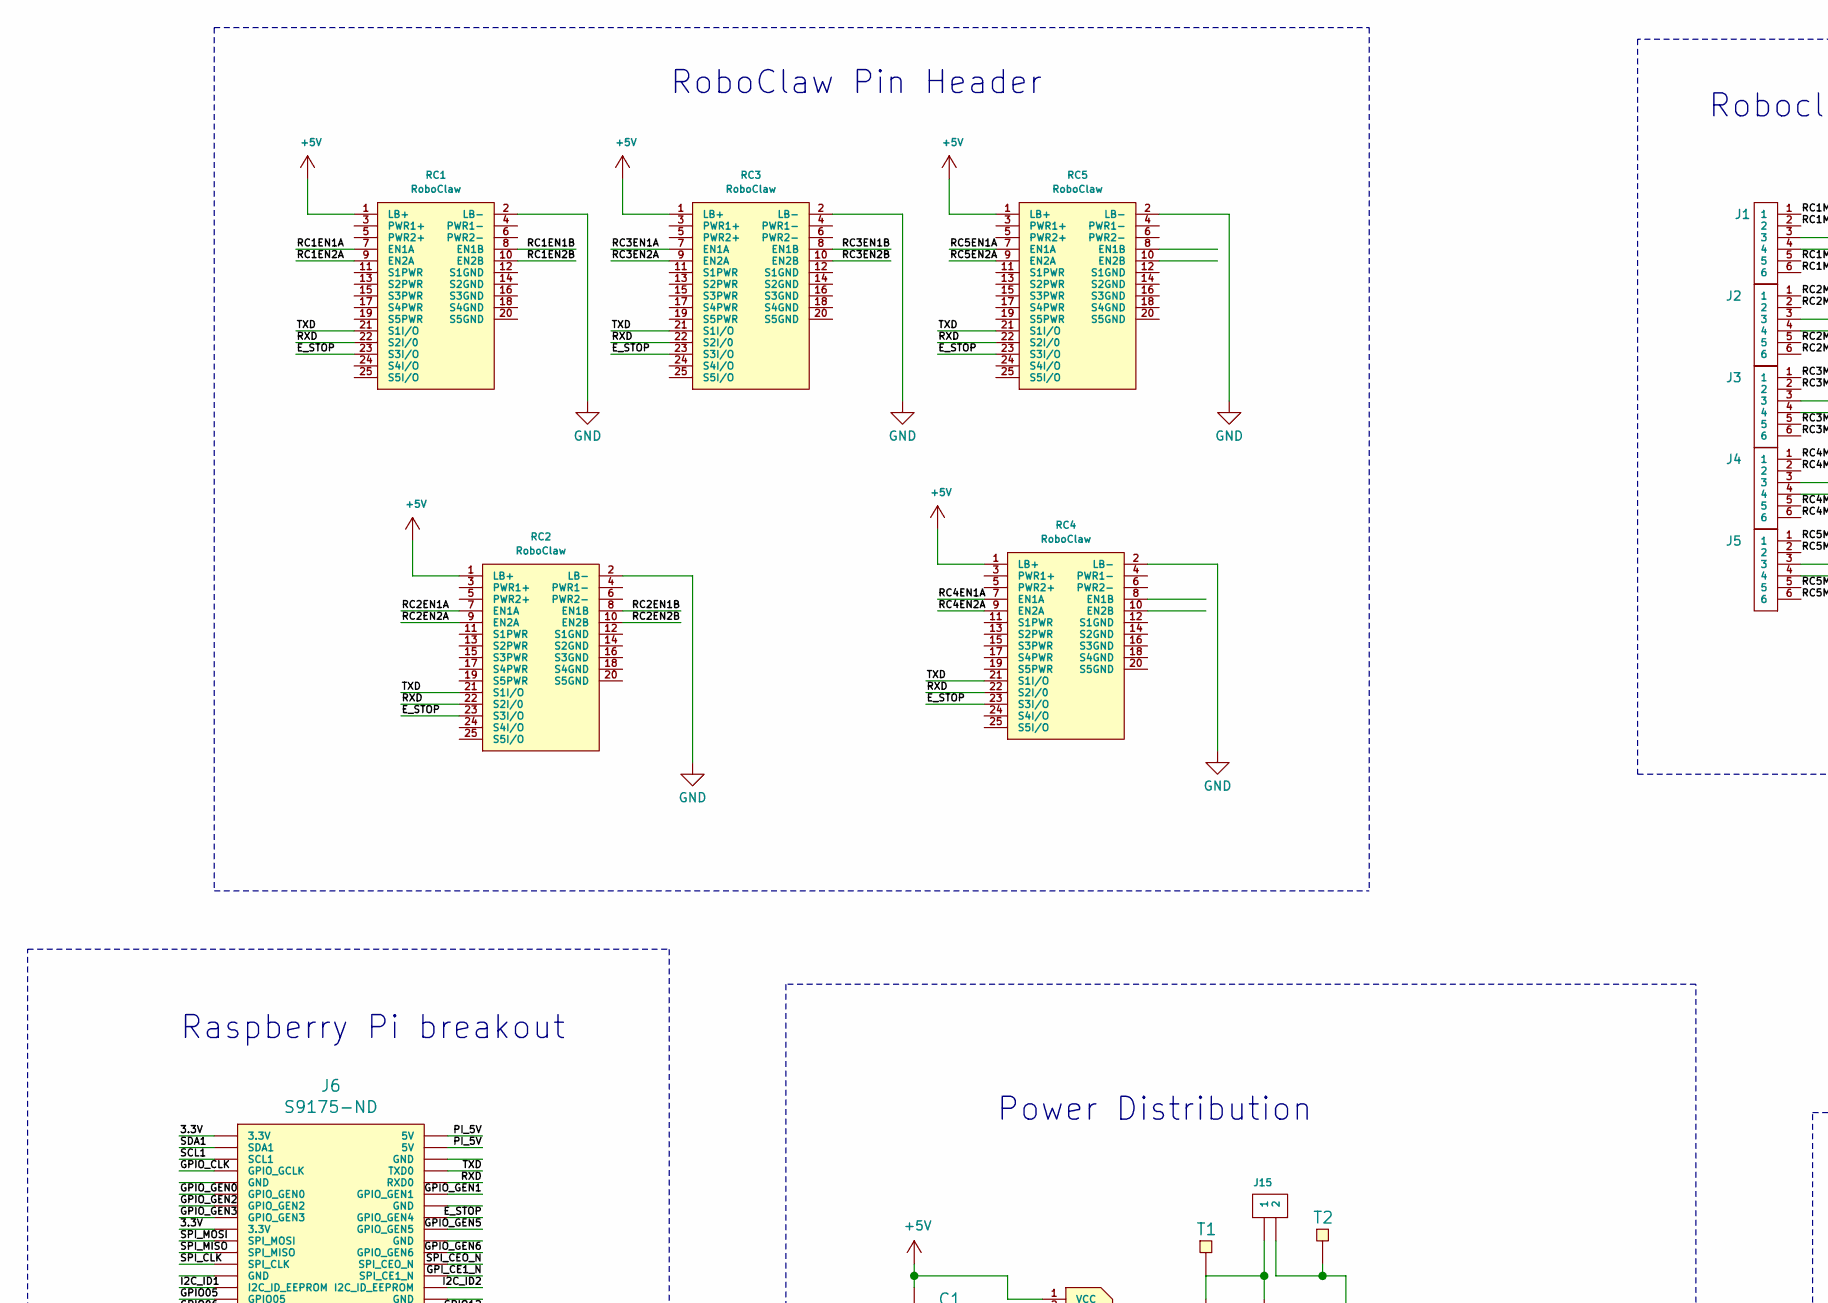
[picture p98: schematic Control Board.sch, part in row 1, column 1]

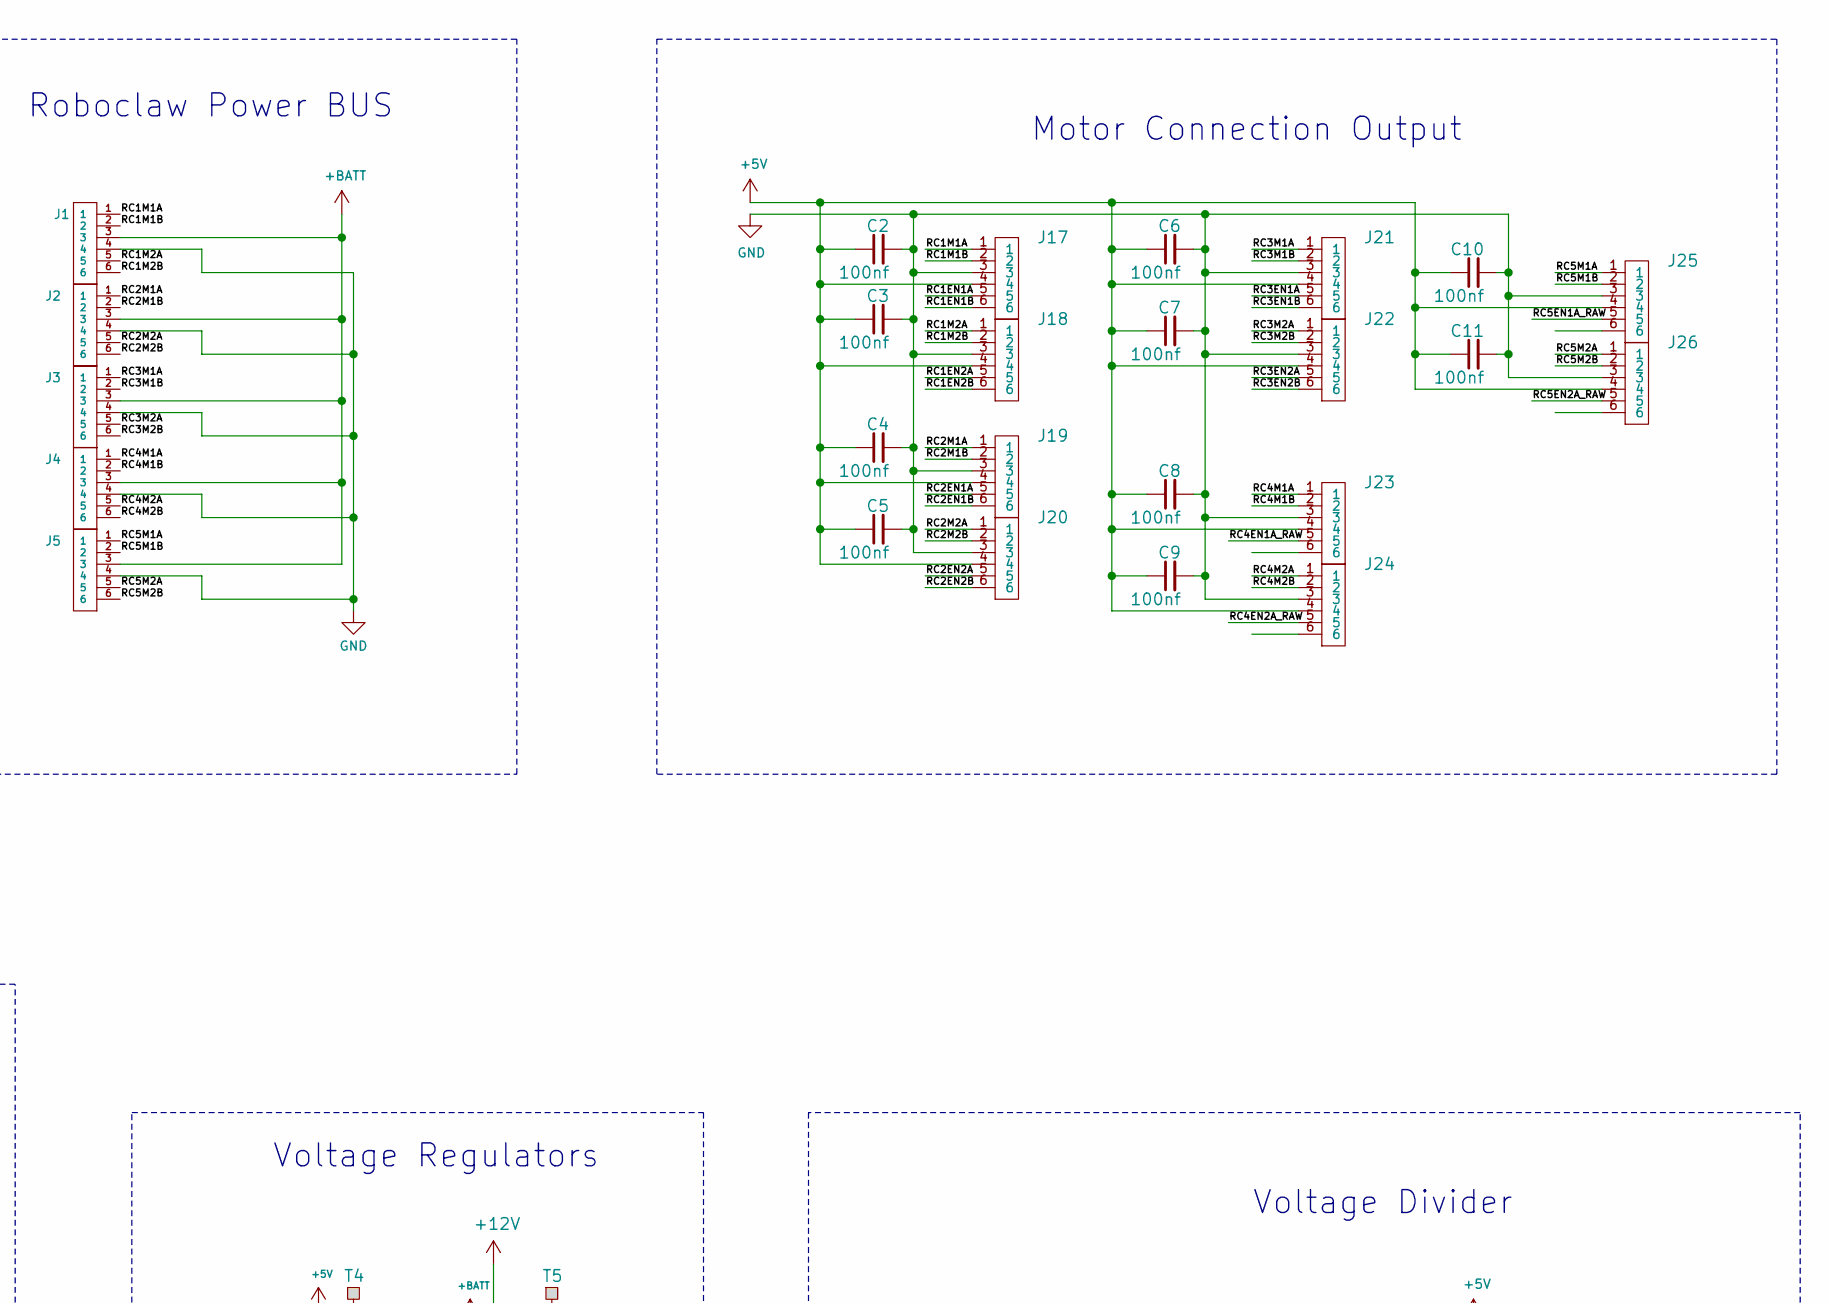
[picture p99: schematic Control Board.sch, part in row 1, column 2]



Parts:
C1: 0.1mF; R_Axial_DIN0207_L6.3mm_D2.5mm_P7.62mm_Horizontal
C2, C3, C4, C5, C6, C7, C8, C9, C10, C11, C16, C17: 100nf; R_Axial_DIN0207_L6.3mm_D2.5mm_P7.62mm_Horizontal
C12, C13, C14, C15: 100nF; R_Axial_DIN0207_L6.3mm_D2.5mm_P7.62mm_Horizontal
D1: D; 497-2738-5-ND
F1: Fuse; 507-1937-1-ND
J1, J2, J3, J4, J5: ED2627-ND
J6, J7: S9175-ND
J8: 6posheader; 6x1 Header Pin 0.1 Pitch
J9: S7038-ND
J10: 6posheader; 455-1708-ND
J11: S7038-ND; D24V22F12 Regulator
J12, J14: ED2989-ND-USB; ED2989-ND USB Conn
J13: ED1501-ND
J15, J16: ED2580-ND
J17, J18, J19, J20, J21, J22, J23, J24, J25, J26: ED2744-ND
M1: Mounting_Holes; Raspberry pi footprint
MH1, MH2, MH3, MH4: #6THRU-HOLE
R1: 4.7K; R_Axial_DIN0207_L6.3mm_D2.5mm_P7.62mm_Horizontal
R2, R4, R6, R8, R10: 10K; R_Axial_DIN0207_L6.3mm_D2.5mm_P7.62mm_Horizontal
R3, R5, R7, R9: 22K; R_Axial_DIN0207_L6.3mm_D2.5mm_P7.62mm_Horizontal
RC1, RC2, RC3, RC4, RC5: RoboClaw; Roboclaw Mount
T1, T2, T3, T4, T5, T6, T7, T8, T9, T10, T11, T12, T13, T14, T15, T16, T17, T18, T19, T20, T21: test_point; TestPoint_Pad_1.0x1.0mm
U1, U2: LM358-N; AE9986-ND
y1: rover_silkscreen; rover_image

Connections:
+5V: C1.1, C2.1, C3.1, C4.1, C5.1, C6.1, C7.1, C8.1, C9.1, C10.1, C11.1, C16.1, C17.1, J9.5, J10.2, J12.1 (VCC), J14.1 (VCC), J17.4, J18.4, J19.4, J20.4, J21.4, J22.4, J23.4, J24.4, J25.4, J26.4, R1.2, RC1.1 (LB+), RC2.1 (LB+), RC3.1 (LB+), RC4.1 (LB+), RC5.1 (LB+), T4.1, T13.1, U1.8 (VCC), U2.8 (VCC)
+12V: J10.1, J11.5, J13.1, T5.1
+BATT: J1.3, J2.3, J3.3, J4.3, J5.3, J9.2, J11.3, J16.2, R2.2; also elsewhere on the board
/3.3V: J6.1 (3.3V), J6.17 (3.3V), J7.1 (3.3V), J7.17 (3.3V)
/5REG_EN: J9.1
/12REG_EN: J11.2
/CTS#: J8.2
/E_STOP: J6.16 (GPIO_GEN4), RC1.23 (S3I/O), RC2.23 (S3I/O), RC3.23 (S3I/O), RC4.23 (S3I/O), RC5.23 (S3I/O)
/GPIO05: J6.29 (GPIO05), J7.29 (GPIO05)
/GPIO06: J6.31 (GPIO06), J7.31 (GPIO06)
/GPIO12: J6.32 (GPIO12), J7.32 (GPIO12)
/GPIO13: J6.33 (GPIO13), J7.33 (GPIO13)
/GPIO16: J6.36 (GPIO16), J7.36 (GPIO16)
/GPIO19: J6.35 (GPIO19), J7.35 (GPIO19)
/GPIO20: J6.38 (GPIO20), J7.38 (GPIO20)
/GPIO21: J6.40 (GPIO21), J7.40 (GPIO21)
/GPIO26: J6.37 (GPIO26), J7.37 (GPIO26)
/GPIO_CLK: J6.7 (GPIO_GCLK), J7.7 (GPIO_GCLK)
/GPIO_GEN0: J6.11 (GPIO_GEN0), J7.11 (GPIO_GEN0)
/GPIO_GEN1: J6.12 (GPIO_GEN1), J7.12 (GPIO_GEN1)
/GPIO_GEN2: J6.13 (GPIO_GEN2), J7.13 (GPIO_GEN2)
/GPIO_GEN3: J6.15 (GPIO_GEN3), J7.15 (GPIO_GEN3)
/GPIO_GEN5: J6.18 (GPIO_GEN5), J7.18 (GPIO_GEN5)
/GPIO_GEN6: J6.22 (GPIO_GEN6), J7.22 (GPIO_GEN6)
/GPI_CE1_N: J6.26 (SPI_CE1_N), J7.26 (SPI_CE1_N)
/I2C_ID1: J6.27 (I2C_ID_EEPROM), J7.27 (I2C_ID_EEPROM)
/I2C_ID2: J6.28 (I2C_ID_EEPROM), J7.28 (I2C_ID_EEPROM)
/PG: J11.1
/PI_5V: J6.2 (5V), J6.4 (5V), J7.2 (5V), J7.4 (5V)
/RC1EN1A: J17.5, RC1.7 (EN1A)
/RC1EN1B: J17.6, RC1.8 (EN1B)
/RC1EN2A: J18.5, RC1.9 (EN2A)
/RC1EN2B: J18.6, RC1.10 (EN2B)
/RC1M1A: J1.1, J17.1
/RC1M1B: J1.2, J17.2
/RC1M2A: J1.5, J18.1
/RC1M2B: J1.6, J18.2
/RC2EN1A: J19.5, RC2.7 (EN1A)
/RC2EN1B: J19.6, RC2.8 (EN1B)
/RC2EN2A: J20.5, RC2.9 (EN2A)
/RC2EN2B: J20.6, RC2.10 (EN2B)
/RC2M1A: J2.1, J19.1
/RC2M1B: J2.2, J19.2
/RC2M2A: J2.5, J20.1
/RC2M2B: J2.6, J20.2
/RC3EN1A: J21.5, RC3.7 (EN1A)
/RC3EN1B: J21.6, RC3.8 (EN1B)
/RC3EN2A: J22.5, RC3.9 (EN2A)
/RC3EN2B: J22.6, RC3.10 (EN2B)
/RC3M1A: J3.1, J21.1
/RC3M1B: J3.2, J21.2
/RC3M2A: J3.5, J22.1
/RC3M2B: J3.6, J22.2
/RC4EN1A: RC4.7 (EN1A), T11.1, U1.1 (OUTA), U1.2 (-INA)
/RC4EN1A_RAW: J23.5, R3.1, T9.1
/RC4EN2A: RC4.9 (EN2A), T16.1, U1.6 (-INB), U1.7 (OUTB)
/RC4EN2A_RAW: J24.5, R7.1, T20.1
/RC4M1A: J4.1, J23.1
/RC4M1B: J4.2, J23.2
/RC4M2A: J4.5, J24.1
/RC4M2B: J4.6, J24.2
/RC5EN1A: RC5.7 (EN1A), T12.1, U2.1 (OUTA), U2.2 (-INA)
/RC5EN1A_RAW: J25.5, R5.1, T10.1
/RC5EN2A: RC5.9 (EN2A), T17.1, U2.6 (-INB), U2.7 (OUTB)
/RC5EN2A_RAW: J26.5, R9.1, T21.1
/RC5M1A: J5.1, J25.1
/RC5M1B: J5.2, J25.2
/RC5M2A: J5.5, J26.1
/RC5M2B: J5.6, J26.2
/RTS#: J8.6
/RXD: J6.10 (RXD0), J7.10 (RXD0), R1.1, RC1.22 (S2I/0), RC2.22 (S2I/0), RC3.22 (S2I/0), RC4.22 (S2I/0), RC5.22 (S2I/0)
/SCL1: J6.5 (SCL1), J7.5 (SCL1)
/SDA1: J6.3 (SDA1), J7.3 (SDA1)
/SPI_CEO_N: J6.24 (SPI_CEO_N), J7.24 (SPI_CEO_N)
/SPI_CLK: J6.23 (SPI_CLK), J7.23 (SPI_CLK)
/SPI_MISO: J6.21 (SPI_MISO), J7.21 (SPI_MISO)
/SPI_MOSI: J6.19 (SPI_MOSI), J7.19 (SPI_MOSI)
/TTL_RXD: J8.5, J10.5
/TTL_TXD: J8.4, J10.4
/TXD: J6.8 (TXD0), J7.8 (TXD0), RC1.21 (S1I/O), RC2.21 (S1I/O), RC3.21 (S1I/O), RC4.21 (S1I/O), RC5.21 (S1I/O)
GND: C1.2, C2.2, C3.2, C4.2, C5.2, C6.2, C7.2, C8.2, C9.2, C10.2, C11.2, C12.1, C13.1, C14.1, C15.1, C16.2, C17.2, J1.4, J2.4, J3.4, J4.4, J5.4, J7.6 (GND), J7.9 (GND), J7.14 (GND), J7.20 (GND), J7.25 (GND), J7.30 (GND), J7.34 (GND), J7.39 (GND), J8.1, J9.3, J9.4, J10.3, J11.4, J12.4 (GND), J13.2, J14.4 (GND), J15.2, J17.3, J18.3, J19.3, J20.3, J21.3, J22.3, J23.3, J24.3, J25.3, J26.3, R4.2, R6.2, R8.2, R10.2, RC1.2 (LB-), RC2.2 (LB-), RC3.2 (LB-), RC4.2 (LB-), RC5.2 (LB-), T2.1, T6.1, T15.1, U1.4 (GND), U2.4 (GND); also elsewhere on the board
unnamed: C12.2, R3.2, R4.1, T7.1, U1.3 (+INA)
unnamed: C13.2, R5.2, R6.1, T8.1, U2.3 (+INA)
unnamed: C14.2, R7.2, R8.1, T18.1, U1.5 (+INB)
unnamed: C15.2, R9.2, R10.1, U2.5 (+INB)
unnamed: D1.1 (K), F1.1, J15.1, T1.1
unnamed: D1.2 (A), F1.2, J16.1, R2.1

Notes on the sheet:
Voltage Divider
Voltage Regulators
Power Distribution
Raspberry Pi breakout
Arduino Communication
Roboclaw Power BUS
Motor Connection Output
RoboClaw Pin Header


Board: 2 copper layers, 154.0 x 175.0 mm, 90 parts (0 on the bottom side), 82 nets.

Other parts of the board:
J16#2: ED2580-ND

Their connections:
+BATT: J16#2.1; also elsewhere on the board
GND: J16#2.2; also elsewhere on the board

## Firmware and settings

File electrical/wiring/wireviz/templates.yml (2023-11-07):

templates:
  Molex-to-PCB: &molex
    type: Molex Mini-Fit Jr.
    subtype: female
    pinlabels: [M+, M-, G, 5V, EnA, EnB]
    show_pincount: true
    image:
      src: ./connector_images/Molex-Mini-Fit-Jr-6.png
      caption: Molex Pinout
      width: 165
  Motor-to-Molex: &bullet
    type: Bullet
    show_pincount: false
  Male-DuPont-4pin: &maleDP4
    type: DuPont
    subtype: male
    pinlabels: [5V, GND, EnA, EnB]
    show_pincount: true
    image:
      src: ./connector_images/DuPont-4.png
      caption: Dupont Pinout
      width: 300
      height: 200
  Female-DuPont-4pin: &femDP4
    type: DuPont
    subtype: female
    pinlabels: [5V, GND, EnA, EnB]
    show_pincount: true
    image:
      src: ./connector_images/DuPont-4.png
      caption: Dupont Pinout
      width: 300
      height: 200
  Male-DuPont-3pin: &maleDP3
    type: DuPont
    subtype: male
    pinlabels: [PWM, +, GND]
    show_pincount: true
    image:
      src: ./connector_images/DuPont-3.png
      caption: Dupont Pinout
      width: 300
      height: 200    
  Female-DuPont-3pin: &femDP3
    type: DuPont
    subtype: female
    pinlabels: [PWM, +, GND]
    show_pincount: true
    image:
      src: ./connector_images/DuPont-3.png
      caption: Dupont Pinout
      width: 300
      height: 200
  JST-XH: &jst_xh4
    type: JST-XH
    subtype: female
    pinlabels: [EnB, EnA, GND, 5V]
    image:
      src: ./connector_images/JST-XH4.png
      caption: JST-XH Pinout
      width: 231
      height: 202
  Encoder: &enc
    colors: [RD, BK, BU, WH]
    gauge: 22 awg
  Servo: &servo
    colors: [WH, RD, BK]
    gauge: 20 awg
  Motor: &motor
    colors: [RD, BK]
    gauge: 18 awg 

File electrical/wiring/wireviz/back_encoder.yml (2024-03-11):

connectors:
  Molex-to-PCB:
    <<: *molex
  M+-to-Molex:
    <<: *bullet
    pinlabels: [M+]
  M--to-Molex:
    <<: *bullet
    pinlabels: [M-]
  Encoder-to-Molex: 
    <<: *femDP4

cables:
  W1: 
    <<: *motor
    length: 41 cm

  W2: 
    <<: *enc
    length: 46 cm

connections:
  - 
    - Molex-to-PCB: [1]
    - W1: [1]
    - M+-to-Molex: [1]
  - 
    - Molex-to-PCB: [2]
    - W1: [2] 
    - M--to-Molex: [1]
  -
    - Molex-to-PCB: [4, 3, 5, 6]
    - W2: [1-4]
    - Encoder-to-Molex: [1, 2, 3, 4]

metadata:
  title: Back Encoder Cable (x2)

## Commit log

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2018-04-03 Updating all necessary files of CAD. Also fixed an issue in the body assembly with the custom acrylic backplate, updated the parts list and build doc to reflect this change. Added breif section in co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
    [0.5 Bore Side Tapped Clamping Hub.SLDASM, 4.5 x 12 Alumin Pattern Plate Mod x2.SLDPRT, Back body plate.DXF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]
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2018-04-05 updating the Software steps pdf to include steps to get the android app, and reorganized a bit of the sections in this document
    [osr_Master_parts_list.xlsx]
2018-04-06 breaking the electrical parts list off into its' own section as well
    [Electrical Parts List.xlsx, osr_Master_parts_list.xlsx]
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2018-04-16 Updating 0.5 inch aluminum rod to have thicker wall diameter in the parts lists
    [Mechanical Integration Parts List.xlsx, osr_Master_parts_list.xlsx]
2018-04-16 Updating the calibration document to reflect the new process withe the linear voltage division boards
    [4.5 x 12 Aluminum Pattern Plate Mod.SLDPRT]
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2018-08-02 Fixes #4 with inconsistancy of resistor links in electrical parts list. Also removed un maintained parts lists in the master parts list
    [Electrical Parts List.xlsx, osr_Master_parts_list.xlsx]
2018-08-02 body assembly link is broken
    added %20 (spaces) to fix.
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2018-08-03 Fixed Absolute Encoder price
    [osr_Master_parts_list.xlsx]
2018-08-03 Closes Issue #9 by adding a Digikey_BOM.csv file that you can upload to the digikey website
    [Digikey_BOM.csv]
2018-08-03 Closes issue #8 by removing the motor gearbox inconsistency between the wishlist and master parts list. The motor suggested is the 172:1 Gearbox
    [osr_Master_parts_list.xlsx]
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2018-09-18 Closes #41 by increasing hole size on serial splitter board to be 4-40 thru holes, updating the part used for the 5V regulator (previous part was incorrect part number), and updating corresponding mo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
    [5V Buck Boost Converter.SLDPRT, Custom AL sheet.SLDPRT, Electronics Board Assembly.SLDASM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]
2018-09-20 Closes Issue #44 by removing the Rover 3D view.pdf document, it appears as though the CAD file is too large to generate the 3D pdf of entire rover, will search for a better solution
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2018-10-02 Added total price and set order of fields in the master parts list
    [master_parts_list.csv, parts_list_reference.csv]
2018-10-02 Fixed parts count
    [master_parts_list.csv, parts_list_reference.csv]
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2018-10-02 Fixed typos and added defaults for missing parts
    [master_parts_list.csv, parts_list_reference.csv]
2018-10-10 Fixing wiring diagram of motor/encoders for the corner system per Issue #54
    [25mm Motor and Encoder.SLDPRT]
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2018-11-21 4.5 inch channel had wrong link in Column L
    [osr_Master_parts_list.xlsx]
2018-12-06 Fixed incorrect reference to 24AWG wire in Electrical Build doc. Closes #61.
2018-12-06 Adding a dummy commit, this is from opening CAD and saving files, thus changing the timestamp of parts
    [0.5 Pillow Bearing Block.SLDASM, 25m Bore Side Tapped Clamping Mount.SLDASM, Electronics Board Assembly.SLDASM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]
2018-12-07 Updated parts list to include correct links to 30AWG wire. Closes #66 and resolves #61.
    [Electrical Parts List.xlsx, osr_Master_parts_list.xlsx]
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2018-12-14 Removing T2 spacer/standoff (3/8 inch standoff) as an unused part. Also updated the Rocker-bogie build doc to have the correct reference in secion 2.2
    [osr_Master_parts_list.xlsx]
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2018-12-28 Fix incorrect pins for testing voltage divider
2019-01-14 Added missing reference to Logic Shifter custom PCB in master BOM
    [osr_Master_parts_list.xlsx]
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2019-03-11 Fixing issue 99, adding b3 screw to directions
2019-03-11 Issue 98 - Reoriding the steps in section 2 of the wheel assembly. I believe the current instructions (attaching the gear, d-clamp, etc) after the 4.5 inch channel has been attached to the wheel asse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
2019-03-11 Added parts list tables to all Electrical build documents. Fixed duplicate project ref codes.
    [master_parts_list.csv, parts_list_reference.csv]
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2019-03-12 Now generating formatted .xlsx file to match original parts list. Finalized build_parts_list.py.
    [master_parts_list.xlsx, master_parts_list_raw.csv, osr_Master_parts_list.xlsx]
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2019-03-14 Updating the auto-generated parts list program. Moving the logic and required files into their own directory while providing an init script that ensures the users environment has the required librari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
    [master_parts_list.xlsx, master_parts_list_raw.csv, parts_list_reference.csv]
2019-03-14 updating corner steering to use the new shaft clamp, motor, motor mount, etc
    [master_parts_list.xlsx, master_parts_list_raw.csv, parts_list_reference.csv]
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2019-03-23 final commit of all corner steering changes, updated images, CAD files, readme, and more
    [25mm Motor.SLDPRT, 4mm - 0.25in Clamping Shaft Coupler.SLDPRT, 555174 motor mount.STEP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]
2019-04-05 Fixed standoff quantity inconsistency
    [master_parts_list.xlsx, master_parts_list_raw.csv, parts_list_reference.csv]
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2019-04-06 Adding solidworks models and zip files of step/igs files for corner steering update
    [0.25 to 6mm Clamping Coupler.SLDASM, 1_25 threaded standoff.SLDPRT, 25mm Motor.SLDPRT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]
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2019-04-06 Adding Optional CAD parts folder, with some addons developed for the rover
    [arduino plate.DXF, arduino plate.SLDPRT, arduino plate.STEP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]
2019-04-06 Initial dump of fully tested PCB rework information into repo
    [Arduino_uno_sheild-B.Cu.gbr, Arduino_uno_sheild-B.Mask.gbr, Arduino_uno_sheild-B.Paste.gbr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]
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2019-04-24 Creating an initial assembly document about building the Control Board PCB. WIP
    [Electronics-pcb-rework-partslist.xlsx, master_parts_list.xlsx]
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2019-04-29 Fixed model # / link inconsistency for screws in master parts list
    [master_parts_list.xlsx, master_parts_list_raw.csv, parts_list_reference.csv]
2019-04-30 Adding the USB to TTL serial cable to the BOM of the electrical parts list
    [Drive_motor_Assem.SLDASM, Electronics-pcb-rework-partslist.xlsx, custom_drive_motor_mount.SLDPRT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]
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2019-05-08 Updating the Body build instructions to account for the PCB redesign
    [0.5 Bore Bottom Tapped Clamping Mount.SLDASM, 5V regulator.SLDPRT, 6-32_SHCS.SLDPRT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]
2019-05-08 Cleaning up CAD for Body assembly rework
    [12V Buck Boost Converter.SLDPRT, 4.5 x 12 Alumin Pattern Plate Mod x2.SLDPRT, 4.5 x 12 Aluminum Pattern Plate Mod.SLDPRT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]
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2019-05-22 Uploading fixed version of Drive_motor_mount_v2 for drive motor mounting with servo city motors
    [Drive_motor_Assem.SLDASM, battery holder.STL, drive_motor_cap.STL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]
2019-06-10 Uploading revisions to the pcb assembly docs, as well as restructure of electrical assembly information
    [Arduino_uno_sheild-B.Cu.gbr, Arduino_uno_sheild-B.Mask.gbr, Arduino_uno_sheild-B.Paste.gbr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]
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2019-06-10 Closes #118 by fixing gnd trace for T2 test pad
    [Monolithic Board-B.Cu.gbl, Monolithic Board-B.Mask.gbs, Monolithic Board-B.Paste.gbp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]
2019-06-13 Fixed silkscreen issues on Monolithic Board (Closes 119 and closes 123)
    [Monolithic Board.kicad_pcb]
2019-06-13 Flipped pin labels on arduino board silk screen (resolves 122)
    [Arduino_uno_sheild.kicad_pcb]
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2019-06-21 Adding 5.2mAH battery mount. Updating the Encoder mount to have notches for clamping screw tightenting
    [battery holder_5_2maH.STL]
2019-06-27 Fixed merge conflict in kicad PCB
    [Monolithic Board.kicad_pcb]
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2019-07-22 Adding CAD files for head rework and pictures to put together
    [10 PORT HEADER.sldprt, 102 RESISTOR PACK.sldprt, 103 RESISTOR PACK.sldprt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]
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2019-07-23 Adding the battery holders, switch, and voltmeter to the body CAD assembly
    [93365A130_HEAT-SET INSERTS FOR PLASTICS.SLDPRT, Battery holder_5_2mAH.SLDASM, back_panel.SLDPRT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]
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2019-07-24 Updating the parts list reference sheet with all new parts for PCB rework, removing unused parts
    [parts_list_reference(old-rev).csv, parts_list_reference.csv]
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2019-07-25 Fixing part reference to heat set inserts
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2019-07-26 Adding board Rev-E of control board with updated silkscreen images, and Rev-D of arduino board also with silk screen fixes
    [Arduino_uno_sheild-B.Cu.gbr, Arduino_uno_sheild-B.Mask.gbr, Arduino_uno_sheild-B.Paste.gbr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]
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2019-07-26 Final update of master parts list for electronics PCB rework
    [Electronics-pcb-rework-partslist.xlsx, master_parts_list.xlsx, master_parts_list_raw.csv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]
2019-07-26 Fixed compilation warnings in PCB Assembly.tex
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2019-07-26 Changed to shorter screws for wheel assembly. Closes #125
    [master_parts_list.xlsx, master_parts_list_raw.csv]
2019-07-26 Closes Issue #137 by fixing build doc pictures
    [Monolithic Board-B.Cu.gbl, Monolithic Board-B.Mask.gbs, Monolithic Board-B.Paste.gbp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]
2019-08-03 Fixes #143 by fixing referece to voltage regulator standoff to be T8 instead of T6
2019-08-06 Removed duplicated steps for attaching diff pivot. Fixes #148.
    [master_parts_list.xlsx, master_parts_list_raw.csv]
2019-08-06 Fixed images of battery holder installation. Closes #150.
2019-08-06 Fixed orientation of side mounts in Body Build Doc. Fixes #142.
2019-08-06 Added pinout table and image for TTL - Serial cable. Fixes # 153
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2019-09-23 Fixed PVC / PCB typo. Fixes #164.
2019-09-23 Fixed Solder / Soder typo. Closes #165.
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2020-02-17 fix link to PCB files
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2020-04-24 just add all files that I've been using
    will deal with unused files later
    [1108-0002-0002.STEP, 1108-0004-0001.STEP, 1120-0001-0048.STEP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]
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2020-07-27 Opened files in SW2020 + moved gobilda parts to wheel assembly + fixed rover assy
    [0.25 Face Tapped Clamping Hub.SLDPRT, 1206-0016-0004.sldprt, 1401-0043-0032.sldprt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]
2020-09-17 A few updates to electrical docs based on assembly experience (#203)
    * A few updates to electrical docs based on assembly experience:
    - clarified in PCB assembly doc that roboclaw windows driver needs to be installed
    - explicitly stated that the polarity of red/black wires doesn’t matter for the corner motors
    - electrical build section 3, the E29 cable isn’t used - removed that
    part from the table
    - Fixed png file extensions. Previously pdflatex wasn't compiling the docs correctly because file extensions for .png's were treated in a non-case sensitive manner in the .tex docs. This is important in linux, because it's case sensitive. I updated all those references to be lowercase png,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
2020-10-03 init.sh did not work for me, manually adding. Have to use override anyways because no more latex
    [master_parts_list_raw.csv, parts_list_reference.csv]
2020-10-03 Replace picture with updated screenshot for wheel assy readme
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2020-10-04 Remove all those files I checkpointed earlier that aren't part of the assembly
    [0.25 Face Tapped Clamping Hub.SLDPRT, 1108-0002-0002.STEP, 1108-0004-0001.STEP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]
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2020-11-15 Fix missing element in master parts list
    Caused the table to not render.
    [master_parts_list_raw.csv]
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2021-01-14 Fixing wheel assembly readme
2021-01-14 fixing numbering in wheel assembly read me
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2021-04-09 Added laser cut replacement parts and updated documentation
    [bottom_plate_baseline.dxf, top_plate_baseline.dxf]
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2021-05-11 Fix broken link, move to parts_list
    [Digikey_BOM.csv]
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2021-05-22 Fix broken links in Head Assembly documentation
    Closes #289
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2021-06-02 Fix missing files after folder renaming
    [.25 D Shaft.SLDPRT, 0.125in Bore 32 Pitch Shaft Mount Pinion Gear.SLDPRT, 0.25 Beaing Block.SLDPRT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]
2021-06-13 Fix: Errors in parts list
    [master_parts_list_raw.csv]
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2021-06-20 master_parts_list_raw updated for new wire sizes and 3D-printed PVC hubs. Updated electrical_build.md for new wire sized. Added STL of OFF files for PVC hubs.
    [master_parts_list_raw.csv, pvc_hub_lower.STL, pvc_hub_upper.STL]
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2021-06-20 reverted master_parts_list.raw
    [master_parts_list_raw.csv]
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2021-06-20 Removed S50 and S51 to put them in correct PR
    [master_parts_list_raw.csv]
2021-06-20 Fix control board pcb path in kitspace.yaml
2021-06-20 Fixing changes to master parts list csv.
    _Every single line_ was being changed, which is no good. Got rid of all the changes from master, and manually added back in the actual changes of interest.
    [master_parts_list_raw.csv]
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2021-06-24 Missed a nut reference
2021-06-29 fixing line endings yet again
    [master_parts_list_raw.csv]
2021-06-29 fixed line endings in master
    [master_parts_list_raw.csv]
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2021-06-29 fixed pvc_hub_lower.stl
    [pvc_hub_lower.stl]
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2021-06-29 Replace stl files with the correct versions
    [pvc_hub_lower.stl, pvc_hub_upper.stl]
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2021-06-29 fix line endings yet again
    [master_parts_list_raw.csv]
2021-06-29 fix: link to PCB files directory
    Fix broken link to PCB files directory.
2021-07-01 fixed head assembly README.md
2021-07-01 fixed extra item in column problem GitHub complained about in the parts list
    [master_parts_list_raw.csv]
2021-07-02 Changed part refencres for bottom hub to S51 to avoid conflict with plate
    [master_parts_list_raw.csv]
2021-07-02 the correct reference for the bottom hub is S50
    [master_parts_list_raw.csv]
2021-07-02 fixed extra columns in parts list
    [master_parts_list_raw.csv]
2021-07-02 fixed extra columns in parts list row 84
    [master_parts_list_raw.csv]
2021-07-02 fixed extra columns in parts list row 83
    [master_parts_list_raw.csv]
2021-07-03 fix: path to head assembly 3d parts
    Fix path to head Head Assembly 3D parts and make the path a link.
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2021-07-06 Update calibration.md
    Removes LB settings, fixes save settings wording. Closes #332
2021-07-06 Remove duplicate parts S28 and S33 from parts list
    1. Remove S33 as it is a duplicate of S43.
    2. Remove S28 as it is duplicate of S44.
    Closes #334
    [master_parts_list_raw.csv]
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2021-07-07 Spelling corrections
    [master_parts_list_raw.csv]
2021-07-17 Fix Kitspace BOM Arduino shield connector J1
    Closes #341
    [BOM.csv]
2021-08-20 Fix part ref 3D printed PVC clamping hub (top)
    The part ref for 3D printed PVC clamping hub (top) is S24.
2021-12-21 Update master_parts_list_raw.csv
    - Added file location for 3D printed encoded STL file.
    - Updated 4.5x12" plate from servo city (discontinued) to Sculpto
    - Updated T5 part to require 20, instead of 1. Section 3.9 of the PCB Assembly requires 20 for the Roboclaw standoffs but currently the parts list suggests only ordering 1.
    [master_parts_list_raw.csv]
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2022-01-27 Fix screw reference in wheel_assembly
    temporarily use step_5b.png, really should have a new picture
2022-01-27 Add missing views in wheels assy. Close #356
2022-08-16 Update master_parts_list_raw.csv
    The ref code column for row 134 (drive motor) needs to be e49 and not e46, because e46 is a different motor
    [master_parts_list_raw.csv]
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2023-06-26 Fix commas in parts list
    [parts_list.csv]
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2023-07-06 fix csv
    [parts_list.csv]
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2023-07-17 Adding files for control board v2.0.1+2+3, updates to arduino shield, and updates to pcb assembly READMEs
    [12_channel_servo_controller_headers.step, 1726750613.stp, 1760510000.stp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]
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2023-07-25 Write majority of the wiring diagram. Missing some images
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2023-07-26 replace main readme image with rover with bigger wheels
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2023-07-28 Revert "Removed wire link for now"
    This reverts commit 8829a77f3f454f5b3ab71cf3258acceaa93194da.
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2023-09-18 Fixed links to 12/5V regulators
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2023-10-06 Add rev 4 of the body plates, move instructions for laser cutting to extra_parts readme in parts list
    [back_plate_standoff.dxf, bottom_plate.dxf, front_plate_standoff.dxf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]
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2023-10-19 Fixed silkscreen for J18
    [Control_Boards.kicad_pcb]
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2023-11-07 Added short blurb on generating the WireViz diagrams
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2023-11-07 Fix nav link to PCB assembly
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2024-01-09 Update parts_list.csv
    Modified the "short name" on line 54~59.
    Modified the "short name" on line 29 consistent with line 6, "2 Hole U channel".
    [parts_list.csv]
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2024-03-03 Address PR feedback; fix orientation of servo block, add wiring detail
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2024-03-07 Fixing harness diagram for Front and Back Encoder Cables
    [back_encoder.yml, front_encoder.yml]
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2024-04-07 Replace outdated spacer with replacement
    closes #469
    [parts_list.csv]
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2024-12-10 Added clarification about how OnShape model doesn't illustrate perfectly mirrored images of the wheel assemblies.
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2024-12-10 Changed 8mm screw to 6mm as 8mm is too long for this case.
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2024-12-18 added some suggested edits and cleaned up the figure number in pcb-electrical instructions. fixed a few other minor things
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2025-01-03 Fix broken laser cut parts link in parts list readme
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2025-03-17 reworked the directory struction so that it is now expansion/mast/
    [mast_backplate.stl, mast_head-2.stl]
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2025-10-14 improving brain board documentation (#524)
    * add explaination of INA260 connections
    * use updated image
    * add TOC to cut down on scrolling
    * fixing link format
    * formatting
    * easier to trim C32 if installed before J27-29.
    * typo on J24 size
    * detail on pi connection
    * typos
    * add info about USBC pwr cord
    * fix url
    * add info about USBC pwr cord
    * revert image change
    * renumber figs, remove duplicate
    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
2025-11-27 corner assembly (#529)
    * add drill guide
    * notch corner goRail
    * typos, updated CAD link
    * more detail on grommets, wiring assembly order
    * Fix typo in README.md for wheel assembly instructions
    * Update mechanical/wheel_assembly/README.md
    depersonalize wording
    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
2026-08-05 feat: replace hurricane nuts in control arm attachment with goRail nut (#548)
    * feat: replace hurricane nuts in control arm attachment with easier goRail nut (5-hole)
    * docs: md fix
    * docs: fix spelling
    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
    [parts_list.csv]
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
